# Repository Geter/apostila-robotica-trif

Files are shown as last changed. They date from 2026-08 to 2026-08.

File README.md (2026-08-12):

# Apostila de Robótica — TRIF 2026

Material didático para o desenvolvimento de robôs **Seguidor de Linha** e **Sumô 500 g** visando a participação no **Torneio de Robótica do IFSP (TRIF)**.

Desenvolvido no âmbito do projeto de Bolsa de Ensino **"Aprendizado baseado em projetos: criando soluções para problemas reais"** — IFSP Câmpus Campos do Jordão.

> **Nota sobre os regulamentos:** o edital e os regulamentos do TRIF 2026 (7ª edição) ainda não foram publicados. Esta apostila utiliza como referência os documentos da 6ª edição (Edital nº 187/2025 e regras revisadas em 28/08/2025), disponíveis na pasta [`regulamentos/`](regulamentos/). Ao serem publicados os documentos de 2026, verifique possíveis mudanças — especialmente dimensões, pesos e especificações técnicas.

## Estrutura do repositório

| Pasta | Conteúdo |
|---|---|
| [`apostila/`](apostila/) | Capítulos da apostila em Markdown |
| [`codigo/testes-unitarios/`](codigo/testes-unitarios/) | Sketches para testar cada componente isoladamente |
| [`codigo/evolutivos/`](codigo/evolutivos/) | Versões progressivas dos programas dos robôs |
| [`codigo/playground/`](codigo/playground/) | Algoritmos simples e abertos à criação do aluno |
| [`codigo/competicao/`](codigo/competicao/) | Algoritmos otimizados para o dia da competição |
| [`modelos-3d/`](modelos-3d/) | Arquivos STL das peças impressas em 3D |
| [`regulamentos/`](regulamentos/) | Edital e regras oficiais do TRIF (referência 2025) |
| [`docs/`](docs/) | Imagens e diagramas utilizados na apostila |

## Sumário da apostila

1. [Apresentação](apostila/00-apresentacao.md)
2. [Capítulo 1 — Eletrônica básica](apostila/01-eletronica-basica.md)
3. [Capítulo 2 — Programação com Arduino](apostila/02-programacao-arduino.md)
4. [Capítulo 3 — Seguidor de linha](apostila/03-seguidor-de-linha.md)
5. [Capítulo 4 — Sumô 500 g](apostila/04-sumo-500g.md)
6. [Capítulo 5 — Montagem e integração](apostila/05-montagem-e-integracao.md)
7. [Capítulo 6 — Testes e desempenho](apostila/06-testes-e-desempenho.md)
8. [Anexos](apostila/anexos.md)

## Plataforma de hardware

Os projetos utilizam **Arduino Micro (ATmega32U4)**, motores **N20** com rodas **StickyMAX S20 22 mm**, módulo sensor **infravermelho de 8 canais**, ponte H **L298N**, regulador **LM2596** e bateria **LiPo 2S 2200 mAh**. A lista completa de materiais está nos [Anexos](apostila/anexos.md).

> 💡 **Sugestão de upgrade:** o **ESP32** é uma alternativa mais moderna, com Bluetooth nativo (útil para a modalidade Sumô RC), mais memória e menor custo. Os códigos exigem pequenas adaptações de pinagem e de leitura analógica (faixa 0–4095).

## Como abrir os códigos

Cada sketch está em sua própria pasta (padrão exigido pela Arduino IDE). Abra o arquivo `.ino` diretamente pela IDE. Selecione a placa **Arduino Micro** em *Ferramentas → Placa*.

## Status

| Item | Situação |
|---|---|
| Seguidor de linha (hardware, peças 3D, códigos) | ✅ Completo |
| Sumô — conceitos, regulamento, sensores, códigos de referência | ✅ Completo |
| Sumô — chassi, bateria e driver de motor | 🚧 **Em desenvolvimento** |
| Fotos da placa de distribuição de energia | 🚧 A adicionar |

## Autoria

Prof. Geterson Policarpo Nunes — IFSP Câmpus Campos do Jordão.
Projeto coordenado em conjunto com o Prof. Marques Moreira de Sousa.

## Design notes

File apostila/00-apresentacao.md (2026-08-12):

# Apresentação

## O que é esta apostila

Esta apostila orienta o desenvolvimento de dois robôs de competição — um **Seguidor de Linha** e um **Sumô de 500 g** — para participação no **Torneio de Robótica do IFSP (TRIF)**, edição 2026. Ela nasceu dentro do projeto de Bolsa de Ensino *"Aprendizado baseado em projetos: criando soluções para problemas reais"*, do IFSP Câmpus Campos do Jordão, e serve de material de apoio às oficinas práticas de robótica realizadas nos laboratórios de Informática e Robótica do câmpus.

> ⚠️ **Referência normativa:** como o edital e os regulamentos do TRIF 2026 ainda não foram publicados, todo o conteúdo normativo desta apostila baseia-se nos documentos da 6ª edição (2025). O histórico do torneio mostra que as regras mudam entre edições — o Sumô, por exemplo, já migrou da categoria 1 kg / 20×20 cm para 500 g / 10×10 cm. **Verifique os documentos oficiais de 2026 assim que forem publicados.**

## Para quem ela foi escrita

Para dois públicos que se encontram nas oficinas:

- **Monitores e bolsistas do projeto** — estudantes do ensino superior ou do técnico integrado que se preparam com a apostila para conduzir as oficinas. O único pré-requisito assumido é lógica de programação básica.
- **Participantes das oficinas** — estudantes que seguirão a apostila como guia de construção dos robôs.

O texto fala diretamente com você, leitor, seja qual for o seu papel. A apostila foi pensada para ser **autossuficiente**: tudo o que é necessário para construir e programar os robôs está aqui ou no repositório que a acompanha.

## Cultura maker: produzir em vez de comprar

O princípio que atravessa todo o material é simples: **tudo o que puder ser produzido, nós produziremos**. O chassi é impresso em 3D. A pista de treino é feita à mão. A placa de distribuição de energia é soldada por você. Comprar pronto é o último recurso, não o primeiro. Essa escolha não é apenas econômica — é pedagógica: quem constrói entende, e quem entende conserta, melhora e cria.

## Como a apostila funciona

**Testes a cada passo.** Todo item prático termina com um bloco **"🧪 Teste o que você fez"** — uma verificação imediata do que foi implementado antes de avançar. Mediu a tensão? O sensor apareceu no monitor serial? O motor girou nos dois sentidos? Nenhum componente entra no robô sem passar no seu teste isolado. Esse é o mesmo princípio dos testes de software profissionais: encontrar o erro cedo, quando ele ainda é pequeno e barato.

**Simule antes de montar.** Nos capítulos 1 e 2, o fluxo de trabalho é sempre: **simular → montar → testar**. Usamos o [Tinkercad](https://www.tinkercad.com/) para experimentar circuitos e códigos virtualmente antes de tocar em qualquer componente físico.

**O problema vem antes da solução.** Cada conteúdo parte de uma necessidade concreta do robô. Você não estuda PWM "porque sim" — estuda porque precisa controlar a velocidade do motor.

**Espaço para as suas soluções.** A apostila entrega caminhos que funcionam, mas deixa deliberadamente espaços de criação: o desafio da placa de distribuição de energia (Capítulo 5), os códigos *playground* com pontos de modificação, e a seção de soluções do aluno, onde cada equipe documenta e justifica as próprias escolhas.

## O objetivo concreto

Ao final do percurso, você terá construído robôs aptos a competir nas modalidades **Robôs Seguidores de Linha** e **Sumô de Robôs (500 g)** do TRIF, com potencial de apresentação na SNCT e em outras competições. Mais importante: terá percorrido o ciclo completo de um projeto de engenharia — do requisito ao teste de desempenho.

## Roteiro de leitura

| Capítulo | Conteúdo | Modo de leitura |
|---|---|---|
| 1 — Eletrônica básica | Fundamentos elétricos, componentes, Arduino, motores | Sequencial |
| 2 — Programação com Arduino | IDE, estrutura de código, entradas/saídas, práticas | Sequencial |
| 3 — Seguidor de linha | Projeto completo da modalidade | Por modalidade |
| 4 — Sumô 500 g | Projeto completo da modalidade | Por modalidade |
| 5 — Montagem e integração | Motores, fiação, baterias, desafio de energia | Transversal |
| 6 — Testes e desempenho | Metodologia de testes e preparação para a competição | Fechamento |
| Anexos | Lista de materiais, pinagens, glossário | Consulta |

Os capítulos 1 e 2 são a fundação — leia-os na ordem. Os capítulos 3 e 4 são independentes entre si. Os capítulos 5 e 6 servem aos dois robôs.

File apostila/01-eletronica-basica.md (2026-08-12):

# Capítulo 1 — Eletrônica básica

Antes de qualquer robô andar, existe eletricidade fluindo por fios, resistores, sensores e motores. Este capítulo constrói o vocabulário e as habilidades de bancada que você usará em todo o resto da apostila.

## 1.1 Conceitos fundamentais de eletricidade

### Cargas elétricas

Toda a eletricidade nasce das cargas elétricas presentes na matéria:

- **Próton** — carga positiva ( + )
- **Elétron** — carga negativa ( e⁻ )

Cargas de sinais opostos se atraem; de sinais iguais se repelem. É esse desequilíbrio de cargas que faz tudo funcionar.

### Corrente elétrica

**Corrente elétrica é o movimento ordenado dos portadores de carga** (os elétrons) através de um condutor, como um fio ou barramento. Sem uma "força" que os empurre, os elétrons livres de um fio de cobre vagam desordenadamente; quando aplicamos uma diferença de potencial, eles passam a se mover de forma orientada — e isso é corrente.

A corrente é medida em **ampères (A)**:

- 1 ampère = 1 coulomb por segundo
- 1 coulomb = 6,25 × 10¹⁸ elétrons

A corrente pode ser medida com o auxílio de um **multímetro**.

> ⚠️ **Segurança:** é a **corrente** que mata, não a tensão. A tensão por si só, sem circular corrente, não causa dano — o choque elétrico é originado por uma corrente proveniente de uma diferença de potencial. Trate qualquer circuito energizado com respeito.

**Corrente contínua (CC/DC)** flui sempre no mesmo sentido — é o caso de pilhas, baterias e de tudo nos nossos robôs. **Corrente alternada (CA/AC)** inverte o sentido periodicamente — é a da tomada da sua casa. Nesta apostila, trabalharemos exclusivamente com corrente contínua.

### Tensão (diferença de potencial)

A **tensão** é a "pressão elétrica" que empurra os elétrons. É medida em **volts (V)**. Exemplos do cotidiano: uma bateria de carro tem 12 V; a tomada, 127 V ou 220 V. No robô, trabalharemos com tensões entre 5 V e 8,4 V.

### Resistência elétrica

**Resistência é a capacidade de um condutor de se opor e dificultar a passagem da corrente elétrica.** Ela é obtida por meio de **resistores**, componentes que transformam energia elétrica em energia térmica. A resistência é medida em **ohms**, cujo símbolo é **Ω** (ex.: 1 kΩ = 1000 Ω).

### A Lei de Ohm

A relação entre as três grandezas é a lei mais importante da eletrônica:

```
V = R × I
```

| Grandeza | Símbolo | Unidade |
|---|---|---|
| Tensão | V (ou U) | volt (V) |
| Corrente | I | ampère (A) |
| Resistência | R | ohm (Ω) |

Do triângulo da Lei de Ohm derivam as três formas: `V = I × R`, `I = V / R` e `R = V / I`.

**Exemplo resolvido:** você tem uma bateria de 9 V e quer que uma corrente de 0,05 A flua por um resistor. Qual resistência usar?

```
R = V / I = 9 / 0,05 = 180 Ω
```

### Prefixos métricos

Na eletrônica, os números variam de milionésimos a milhões — por isso usamos prefixos:

| Prefixo | Símbolo | Fator |
|---|---|---|
| mega | M | ×1.000.000 |
| quilo | k | ×1.000 |
| — | — | ×1 |
| mili | m | ÷1.000 |
| micro | µ | ÷1.000.000 |

Exemplos: 1.000 volts = 1 kV; 0,003 ampères = 3 mA.

### ✏️ Exercícios

1. Determine a diferença de potencial em um fio condutor com resistência de 20 Ω, por onde passa uma corrente de 5 A.
2. Um engenheiro projeta um sistema de iluminação com lâmpadas LED. Cada lâmpada opera com 12 V e consome 0,5 A. Qual é a resistência elétrica de cada lâmpada?
3. Um equipamento funciona com corrente de 5 A sob 220 V. A empresa mudou-se para um local com rede de 127 V. Considerando a resistência constante, qual será a nova corrente aproximada?
4. Reescreva utilizando prefixos métricos: 1.000 volts; 0,003 ampères; 1.000 GB.

*Pratique mais: [Toda Matéria — exercícios sobre Lei de Ohm](https://www.todamateria.com.br/exercicios-sobre-lei-de-ohm/)*

## 1.2 Circuitos elétricos

### Circuito aberto e fechado

Um **circuito** é o caminho por onde a corrente circula: fonte → condutor → carga → retorno à fonte. Se o caminho está completo, o circuito está **fechado** e a corrente flui. Qualquer interrupção — uma chave desligada, um fio solto — deixa o circuito **aberto** e a corrente cessa. A chave liga/desliga do seu robô fará exatamente isso.

### Associação de resistores

Resistores podem ser conectados **em série** (um após o outro) ou **em paralelo** (conectados em pontos comuns). A forma de conexão determina a resistência total do circuito:

- **Série:** a resistência equivalente é a soma — `Req = R1 + R2 + ...`. A mesma corrente atravessa todos; a tensão se divide entre eles.
- **Paralelo:** para dois resistores — `Req = (R1 × R2) / (R1 + R2)`. A tensão é a mesma em todos; a corrente se divide.
- **Misto:** combinação dos dois casos; resolve-se por partes.

**Exemplo resolvido (série):** 20 Ω e 30 Ω em série com bateria de 30 V → `Req = 50 Ω`, corrente `I = 30/50 = 0,6 A`.

**Exemplo resolvido (paralelo):** 30 Ω e 20 Ω em paralelo → `Req = (30×20)/(30+20) = 600/50 = 12 Ω`.

### Potência elétrica

**Potência** é a taxa de consumo de energia por segundo, medida em **watts (W)** — 1 W = 1 joule por segundo. Na eletricidade:

```
P = V × I
```

**Exemplo:** um circuito com d.d.p. de 20 V e resistor de 100 Ω. Primeiro `I = 20/100 = 0,2 A`; então `P = 20 × 0,2 = 4 W`.

A potência importa no robô: é ela que define quanto os componentes esquecem, quanto a bateria dura e se o regulador de tensão precisa de dissipador.

### ✏️ Exercício

Quatro resistores distintos são associados em série: R1 = 100 Ω, R2 = 50 Ω, R3 = 20 Ω e R4 = 25 Ω, com U = 30 V. Obtenha: (a) a resistência equivalente; (b) a corrente do circuito; (c) as tensões em cada resistor; (d) a potência do sistema.

## 1.3 Ferramentas de bancada

**Protoboard (matriz de contato):** placa de furos interligados internamente que permite montar circuitos sem solda. As linhas laterais (barramentos) distribuem alimentação; as colunas centrais conectam componentes. Ideal para experimentar antes de soldar.

**Multímetro:** o instrumento de medição essencial. Mede tensão (V), corrente (A), resistência (Ω) e continuidade (o "bip" que indica caminho fechado). Regras de ouro:

1. Tensão mede-se **em paralelo** com o componente (pontas nos dois lados dele).
2. Corrente mede-se **em série** (o circuito passa *por dentro* do multímetro).
3. Resistência e continuidade medem-se **com o circuito desenergizado**.
4. Confira a escala e as posições das pontas de prova antes de medir.

**Jumpers:** fios com terminais macho/fêmea para conectar módulos e protoboard.

### Simulador Tinkercad

Antes de montar fisicamente, monte virtualmente. O **Tinkercad Circuits** ([tinkercad.com](https://www.tinkercad.com/)) simula protoboard, Arduino, componentes e até o monitor serial — de graça, no navegador. Todo circuito deste capítulo pode (e deve) ser testado lá primeiro: errar no simulador não queima componente.

> 🧪 **Teste o que você fez** — Crie uma conta no Tinkercad, abra um novo circuito e monte: bateria de 9 V + resistor de 180 Ω. Adicione o multímetro virtual e meça a corrente. O valor deve ser ~0,05 A (50 mA) — exatamente o exemplo da seção 1.1. Bateu? Você acabou de validar a Lei de Ohm na prática.

## 1.4 Componentes essenciais

**Resistores:** limitam corrente. O valor é indicado por faixas coloridas no corpo (use uma tabela de código de cores ou meça com o multímetro — medir é mais rápido e à prova de erro).

**LEDs:** diodos emissores de luz. Têm **polaridade**: o terminal maior é o **ânodo (+)** e o menor, o **cátodo (−)**. Ligar invertido não acende (e não queima); ligar **sem resistor em série** queima. Para 5 V, um resistor de 220 Ω a 330 Ω é o padrão.

**Chaves e botões:** interrompem ou fecham o circuito. O **push-button** (chave táctil) fecha o contato apenas enquanto pressionado; a **chave gangorra** mantém o estado.

**Capacitores:** armazenam energia por curtos períodos. No robô, aparecem "acalmando" a alimentação — falaremos deles no Capítulo 5.

> 🧪 **Teste o que você fez** — No Tinkercad e depois na protoboard física: LED + resistor de 220 Ω + fonte de 5 V. O LED deve acender. Inverta o LED: deve apagar (e nada queima — o resistor está lá). Meça a tensão sobre o LED aceso: deve ficar em torno de 1,8–2,2 V.

## 1.5 A placa Arduino

O **Arduino** é uma plataforma de prototipagem: uma placa com microcontrolador, pinos de entrada/saída e conexão USB, programável em uma linguagem baseada em C++. Nesta apostila usamos o **Arduino Micro**, baseado no chip **ATmega32U4**:

| Característica | Arduino Micro |
|---|---|
| Microcontrolador | ATmega32U4 (AVR 8 bits, 16 MHz) |
| Tensão de operação | 5 V |
| Pinos digitais de I/O | 20 |
| Canais PWM | 7 |
| Entradas analógicas | **12** |
| Memória flash | 32 KB |
| SRAM | 2,5 KB |
| Conexão | micro-USB (nativa no chip) |

O Micro foi escolhido por dois motivos: é compacto (cabe no sumô de 10 cm) e tem **12 entradas analógicas** — o suficiente para os 8 canais do sensor de linha, algo que o popular Arduino Uno (6 analógicas) não oferece nativamente.

**Tipos de pino:**

- **Digitais:** leem ou escrevem apenas dois estados — `HIGH` (5 V) ou `LOW` (0 V).
- **Analógicos (A0–A11):** leem tensões intermediárias, convertidas em números de 0 a 1023.
- **PWM (~):** pinos digitais capazes de simular tensões intermediárias ligando e desligando muito rápido — é assim que controlaremos a velocidade dos motores (Capítulo 2).

> 💡 **Sugestão de upgrade — ESP32:** placa mais moderna, com Wi-Fi e Bluetooth nativos, mais memória e custo menor. Exige adaptações: leitura analógica de 0–4095, pinagem diferente e tensão lógica de 3,3 V. Uma excelente evolução após dominar o Micro — e praticamente obrigatória se você quiser controlar o robô pelo celular na modalidade Sumô RC.

## 1.6 Alimentação: baterias e regulação

O robô carrega a própria energia. Nossa fonte é uma **bateria LiPo 2S** (2 células de lítio-polímero em série): tensão nominal de **7,4 V** (8,4 V com carga cheia), 2200 mAh de capacidade. É leve, potente — e exige cuidados sérios de segurança, detalhados no Capítulo 5.

Só que o Arduino e os sensores trabalham com **5 V**. Entra em cena o **regulador de tensão**: um circuito que converte um nível de tensão em outro. Usaremos o módulo **LM2596 Step Down (buck)**:

| Especificação | LM2596 |
|---|---|
| Tensão de entrada | 4,5 a 40 V |
| Tensão de saída | 1,5 a 36 V, ajustável por trimpot |
| Regra de operação | entrada ≥ saída + 1,5 V |
| Corrente máxima | 3 A |
| Dissipador | recomendado acima de 15 W |

"Step down" significa que a saída é sempre **menor** que a entrada (o inverso é o "step up"). No robô: bateria 7,4 V → LM2596 ajustado para **5,0 V** → Arduino e sensores.

> 🧪 **Teste o que você fez** — Ajuste do LM2596 (procedimento obrigatório antes de conectar qualquer carga):
> 1. Conecte apenas a **entrada** do módulo à bateria (saída sem nada).
> 2. Ligue o multímetro (escala 20 V DC) na saída.
> 3. Gire o trimpot com uma chave pequena observando o display. **Atenção:** o trimpot é multivoltas — em módulos novos pode ser preciso girar dezenas de voltas no sentido anti-horário até a tensão começar a responder.
> 4. Ajuste até ler **5,0 V** estáveis.
> 5. Só então conecte a carga.
>
> Anote a tensão da bateria e a da saída no seu diário de bordo.

## 1.7 Motores DC e ponte H

**Motores DC** giram quando alimentados; invertendo a polaridade, invertem o sentido. Nosso motor é o **N20**, um micro motor com caixa de redução integrada (o conceito de redução é aprofundado no Capítulo 5).

O Arduino, porém, **não pode alimentar um motor diretamente** — seus pinos fornecem no máximo ~40 mA, e um motor exige centenas de mA. A solução é a **ponte H**, um circuito que usa o sinal fraco do Arduino para chavear a corrente forte da bateria, controlando sentido e velocidade. Usaremos o módulo **L298N**:

| Especificação | L298N |
|---|---|
| Tensão de operação (motores) | 6 a 35 V |
| Corrente máxima | 2 A por canal (4 A total) |
| Canais | 2 motores DC |
| Controle de sentido | pinos IN1–IN4 (sinais digitais) |
| Controle de velocidade | pinos ENA/ENB (sinal PWM) |
| Dimensões | ~43 × 43 × 27 mm |

> ⚠️ **Queda de tensão:** o L298N "come" de 1,4 a 2,5 V entre a entrada e o motor. Com a LiPo em 7,4–8,4 V, o motor recebe cerca de 5,4–6,4 V — exatamente a faixa nominal do N20 de 6 V. Por isso, no nosso robô, **a bateria alimenta o L298N diretamente**, sem passar pelo LM2596. A arquitetura completa:

```
                    ┌── LM2596 (5 V) ──→ Arduino Micro + sensores
LiPo 2S ── chave ───┤
                    └── direto ───────→ L298N ──→ motores N20
```

Essa separação tem um bônus: o ruído elétrico gerado pelos motores fica isolado do circuito de lógica e dos sensores.

> 🧪 **Teste o que você fez** — Ainda sem código (isso vem no Capítulo 2), faça o teste elétrico do L298N: alimente o módulo com a bateria (12 V máx. aqui), conecte um motor N20 na saída A e ligue o pino IN1 em 5 V e IN2 em GND (com ENA com o jumper de fábrica). O motor deve girar. Inverta IN1/IN2: gira ao contrário. Você acabou de operar uma ponte H manualmente.

## O que você leva deste capítulo

Tensão empurra, corrente flui, resistência segura — e a Lei de Ohm amarra as três. Você sabe medir com multímetro, montar em protoboard, simular no Tinkercad, e conhece cada bloco de energia e força do robô: bateria, regulador, ponte H e motor. No próximo capítulo, o Arduino ganha vida por código.

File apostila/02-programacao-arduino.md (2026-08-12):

# Capítulo 2 — Programação com Arduino

O hardware do Capítulo 1 só ganha comportamento por meio de código. Aqui você aprende a linguagem do Arduino do zero até controlar motores — sempre no ciclo **simular → montar → testar**.

## 2.1 A IDE do Arduino e o primeiro upload

1. Baixe a **Arduino IDE** em [arduino.cc/en/software](https://www.arduino.cc/en/software) e instale.
2. Conecte o Arduino Micro pelo cabo micro-USB.
3. Em *Ferramentas → Placa*, selecione **Arduino Micro**. Em *Ferramentas → Porta*, selecione a porta que apareceu.
4. Abra *Arquivo → Exemplos → 01.Basics → Blink* e clique em **Carregar** (seta →).

> ⚠️ **Comportamento normal do Micro no upload:** como a USB do ATmega32U4 é nativa no próprio chip, a placa **se desconecta e reconecta** durante a gravação — a porta "some" da lista por alguns segundos e o sistema pode tocar o som de dispositivo removido. Não é defeito. Se um upload falhar, pressione o botão de reset da placa no momento em que a IDE exibir "Carregando..." e tente novamente.

> 🧪 **Teste o que você fez** — O LED da placa deve piscar em intervalos de 1 segundo. Isso valida de uma vez: instalação da IDE, driver, cabo, placa e processo de upload. Guarde este teste — ele será seu "o Arduino está vivo?" para sempre.

## 2.2 Estrutura de um sketch

Todo programa Arduino (chamado de *sketch*) tem duas funções obrigatórias:

```cpp
void setup() {
  // executa UMA vez, quando a placa liga ou reseta
  // aqui configuramos pinos, serial, bibliotecas
}

void loop() {
  // executa em repetição infinita, o mais rápido possível
  // aqui vive o comportamento do robô
}
```

Pense assim: `setup()` é a preparação; `loop()` é a vida do robô — ler sensores, decidir, acionar motores, milhares de vezes por segundo.

## 2.3 Variáveis, condicionais e laços

A linguagem do Arduino é **C++**. O essencial para os robôs:

```cpp
// Tipos de variáveis mais usados
int   velocidade = 150;      // números inteiros (-32768 a 32767)
long  tempo = 0;             // inteiros grandes
bool  linhaDetectada = true; // verdadeiro/falso
float tensao = 7.4;          // números com vírgula

// Constantes: valores que não mudam (pinos, ajustes)
const int PINO_LED = 13;
#define VELOCIDADE_MAXIMA 255

// Condicionais: o "cérebro" das decisões
if (linhaDetectada) {
  // faz algo
} else if (velocidade > 100) {
  // faz outra coisa
} else {
  // caso contrário
}

// Laço: repete enquanto a condição valer
for (int i = 0; i < 8; i++) {
  // executa 8 vezes (i = 0, 1, ... 7) — ler 8 sensores, por exemplo
}
```

## 2.4 Entradas e saídas

### Saída digital — acendendo um LED

LEDs são dispositivos semicondutores que emitem luz quando percorridos por corrente. Lembre-se da polaridade (ânodo +, cátodo −) e do resistor em série. Para controlar um LED por código, usamos uma porta digital e a função `digitalWrite()`:

```cpp
const int PINO_LED = 13;

void setup() {
  pinMode(PINO_LED, OUTPUT);      // declara o pino como saída
}

void loop() {
  digitalWrite(PINO_LED, HIGH);   // 5 V no pino: LED acende
  delay(500);                     // espera 500 ms
  digitalWrite(PINO_LED, LOW);    // 0 V: LED apaga
  delay(500);
}
```

### Entrada digital — lendo um botão

O **push-button** fecha um circuito quando pressionado. Lendo o pino com `digitalRead()`, o código descobre o estado:

```cpp
const int PINO_BOTAO = 5;

void setup() {
  pinMode(PINO_BOTAO, INPUT_PULLUP); // resistor interno: pino fica HIGH solto,
}                                    // e vai a LOW quando o botão (ligado ao GND) é pressionado

void loop() {
  if (digitalRead(PINO_BOTAO) == LOW) {
    // botão pressionado
  }
}
```

### Bounce e debounce

Ao pressionar um botão **uma única vez**, o contato metálico vibra e o microcontrolador pode entender vários acionamentos — esse ruído se chama **bounce**, e causa problemas sempre que o código precisa contar acionamentos. A solução, o **debounce**, ignora mudanças de estado que ocorram num intervalo menor que um tempo mínimo (tipicamente 50 ms), usando a função `millis()` — que retorna quantos milissegundos se passaram desde que o programa começou:

```cpp
bool estadoLed = LOW;
bool leituraAnterior;
bool leituraAtual;
long ultimoTempoPressionado = 0;
long intervaloDebounce = 50;   // ms — ajuste conforme a necessidade

void setup() {
  pinMode(13, OUTPUT);
  pinMode(12, INPUT);
  leituraAtual = digitalRead(12);
}

void loop() {
  leituraAnterior = leituraAtual;
  leituraAtual = digitalRead(12);

  // só aceita a borda se passou tempo suficiente desde a última
  if (leituraAnterior == HIGH && leituraAtual == LOW
      && millis() - ultimoTempoPressionado > intervaloDebounce) {
    estadoLed = !estadoLed;
    digitalWrite(13, estadoLed);
    ultimoTempoPressionado = millis();
  }
}
```

O botão de largada do seu robô usará exatamente essa técnica.

### Entrada analógica

Sensores analógicos entregam tensões intermediárias. `analogRead()` converte 0–5 V em um número de **0 a 1023**:

```cpp
int leitura = analogRead(A0);   // 0 (0 V) a 1023 (5 V)
```

O **monitor serial** é a janela para enxergar essas leituras. Inicialize com `Serial.begin(9600);` no `setup()` e imprima com `Serial.println(leitura);`. Abra o monitor pela lupa no canto da IDE.

> ⚠️ **Particularidade do Micro:** no ATmega32U4, `Serial` é a **porta USB nativa** (monitor serial do computador) e `Serial1` são os **pinos físicos TX/RX**. Tutoriais escritos para o Uno funcionam normalmente com `Serial`; apenas ao conectar um módulo serial externo (ex.: Bluetooth) você usará `Serial1`.

### Saída "analógica" — PWM

Pinos PWM simulam tensões intermediárias ligando e desligando o pino milhares de vezes por segundo. `analogWrite(pino, valor)` aceita **0 a 255**:

```cpp
analogWrite(9, 128);   // ~50% da potência — meia velocidade no motor
```

A função `map()` converte entre faixas — útil para transformar uma leitura analógica (0–1023) em PWM (0–255):

```cpp
int pwm = map(leitura, 0, 1023, 0, 255);
```

## 2.5 Funções e organização do código

Conforme o código cresce, agrupar comportamentos em funções mantém tudo legível — e no robô isso é vital:

```cpp
// Constantes de pinos agrupadas no topo: um único lugar para ajustar
const int ENA = 9, IN1 = 2, IN2 = 3;

void frente(int velocidade) {
  digitalWrite(IN1, HIGH);
  digitalWrite(IN2, LOW);
  analogWrite(ENA, velocidade);
}

void parar() {
  digitalWrite(IN1, LOW);
  digitalWrite(IN2, LOW);
}

void loop() {
  frente(200);
  delay(1000);
  parar();
  delay(1000);
}
```

Todos os códigos deste repositório seguem esse padrão: **constantes de ajuste no topo**, funções curtas com nome que diz o que fazem, e comentários em português.

## 2.6 Práticas guiadas

Cada prática deve ser feita **primeiro no Tinkercad**, depois no hardware real. Os sketches completos estão em [`codigo/testes-unitarios/`](../codigo/testes-unitarios/).

### Prática 1 — Semáforo

Monte três LEDs (verde, amarelo, vermelho) com seus resistores e programe o ciclo de um semáforo. **Desafio extra:** adicione um push-button de pedestre que, pressionado, antecipe o vermelho.

> 🧪 **Teste o que você fez** — O ciclo respeita os tempos programados? O botão responde a um único toque (debounce funcionando)?

### Prática 2 — Leitura de sensor no monitor serial

Monte um potenciômetro no pino A0 e imprima a leitura no monitor serial. Gire e observe os valores de 0 a 1023.

> 🧪 **Teste o que você fez** — Extremo anti-horário ≈ 0, extremo horário ≈ 1023? Anote os valores reais: nenhum componente é perfeito, e conhecer o "zero real" de um sensor é a essência da **calibração** — conceito central no seguidor de linha.

### Prática 3 — Controle de brilho com PWM

Use a leitura do potenciômetro para controlar o brilho de um LED em um pino PWM, com `map()` convertendo 0–1023 em 0–255.

### Prática 4 — Motor com ponte H

Monte o L298N conforme o Capítulo 1 e controle um motor N20 por código: frente, ré, variação de velocidade por PWM. Sketch de referência: [`03_motor_unico_l298n`](../codigo/testes-unitarios/03_motor_unico_l298n/).

> 🧪 **Teste o que você fez** — O motor: gira nos dois sentidos? Para quando comandado? Em PWM 100 gira visivelmente mais devagar que em 255? Em PWM muito baixo (< 60) ele pode nem girar — anote esse limiar: é o **PWM mínimo de partida** do seu motor, um número que você usará nos códigos do robô.

### Prática 5 — Dois motores

Evolua para os dois motores (saídas A e B do L298N) e crie as funções `frente()`, `re()`, `girarEsquerda()`, `girarDireita()` e `parar()`. Sketch: [`04_dois_motores`](../codigo/testes-unitarios/04_dois_motores/).

> 🧪 **Teste o que você fez** — Com o robô **suspenso** (rodas no ar): cada função faz o esperado? Os dois motores giram na mesma velocidade visualmente? Se um for mais lento, anote — a correção por software virá no Capítulo 3.

## O que você leva deste capítulo

Você programa entradas e saídas digitais e analógicas, domina PWM, debounce e monitor serial, e organiza código em funções com constantes no topo. O Arduino deixou de ser uma placa e virou uma ferramenta. Agora, aos robôs.

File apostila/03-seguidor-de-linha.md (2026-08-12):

# Capítulo 3 — Seguidor de linha

O seguidor de linha é a porta de entrada clássica da robótica de competição: um robô autônomo que percorre, no menor tempo possível, um circuito marcado por uma linha no chão. Simples de enunciar, rico de resolver — envolve eletrônica, mecânica, algoritmos e muito ajuste fino.

## 3.1 A modalidade e o regulamento

> ⚠️ Resumo baseado nas **regras do TRIF 2025** (documento completo em [`regulamentos/`](../regulamentos/)). Confirme as regras de 2026 quando publicadas.

**Como funciona a competição:**

- Robô **totalmente autônomo**, com todos os componentes embarcados. Controle externo só para iniciar ou ajustar parâmetros entre tentativas.
- Vence **a volta válida mais rápida** entre todas as tomadas de tempo.
- Cada tomada de tempo dura no máximo **5 minutos**, com **3 tentativas consecutivas**.
- Uma volta é válida quando o robô percorre todo o percurso, **para automaticamente** dentro da área de partida-chegada, sobre a linha, e **permanece parado por pelo menos 2 segundos**.

**O robô:**

| Regra | Valor |
|---|---|
| Dimensões máximas | 250 × 250 × 200 mm |
| Peso | livre |
| Controle | autônomo |
| Downforce (turbina/ventoinha) | permitido, desde que dentro das dimensões |
| Produtos nos pneus para aumentar tração | **proibido** |

**A pista:**

| Característica | Valor |
|---|---|
| Superfície | manta emborrachada **preta** |
| Linha | **branca**, 19 ± 1 mm de largura |
| Comprimento total | até 60 m |
| Geometria | retas e arcos; raio mínimo de 100 mm |
| Cruzamentos | a 90 ± 5°, com retas de 250 mm antes e depois |
| Desníveis tolerados | ± 3 mm; inclinações de até 5° |
| Marcações | **à direita** da linha: partida e chegada; **à esquerda**: mudanças de curvatura |
| Chegada | 1 m atrás da partida, na mesma reta |

> 💡 **Atenção ao detalhe que derruba iniciantes:** em competição a linha é **branca sobre fundo preto** — o oposto da maioria dos tutoriais da internet (linha preta sobre branco). Toda a calibração e a lógica dos nossos códigos já consideram isso.

## 3.2 O sensor de linha: infravermelho refletivo

### Como funciona

Cada canal do sensor tem um par: um **LED emissor infravermelho** e um **fototransistor receptor**. O LED ilumina o chão; o receptor mede quanto refletiu. Superfície **branca reflete muito** (leitura baixa em módulos típicos), superfície **preta absorve** (leitura alta). Comparando as leituras dos canais, o robô descobre **onde a linha está** sob ele.

### Nosso módulo: barra IR de 8 canais

| Especificação | Valor |
|---|---|
| Canais | 8 (saídas analógicas) |
| Dimensões | 66–71 × 16–17 × 4 mm (varia por fabricante) |
| Tensão de operação | 3,3–5 V |
| Consumo | ~100 mA |
| Distância ideal de detecção | **3 mm** |
| Distância máxima | 6 a 9,5 mm |

Por que **8 canais**? Com a linha de 19 mm e sensores espaçados ~8–9 mm, sempre 2 a 3 canais enxergam a linha simultaneamente — o que permite saber a posição dela com precisão e detectar cruzamentos e marcações.

> É por causa desses 8 canais analógicos que usamos o Arduino **Micro** (12 entradas analógicas) e não o Uno (apenas 6).

### Leitura crua

Primeiro passo de qualquer sensor: **ver o que ele vê**. O sketch [`02_leitura_sensor_ir`](../codigo/testes-unitarios/02_leitura_sensor_ir/) imprime os 8 canais no monitor serial.

> 🧪 **Teste o que você fez** — Com o módulo a ~3–5 mm de uma superfície: passe uma folha branca e uma superfície preta sob os sensores e observe os valores. Anote os números típicos de **branco** e de **preto** do *seu* módulo. Há diferença clara entre eles (algumas centenas de unidades)? Se as leituras mal mudam, verifique a distância ao solo e a alimentação.

### Calibração

Módulos reais não são uniformes: cada canal tem seu próprio "branco" e "preto". **Calibrar** é descobrir o mínimo e o máximo de cada canal e normalizar as leituras para uma escala comum (0–1000). O procedimento, implementado em [`01_calibracao`](../codigo/evolutivos/seguidor/01_calibracao/): ao ligar, o robô passeia os sensores sobre linha e fundo por alguns segundos, registrando extremos por canal.

> 🧪 **Teste o que você fez** — Após calibrar, as leituras normalizadas mostram ~0 sobre o branco e ~1000 sobre o preto **em todos os canais**? Um canal que não calibra (fica travado) indica mau contato ou canal defeituoso — descubra agora, não na pista.

## 3.3 Chassi impresso em 3D

### 3.3.1 O conjunto de peças

O chassi do seguidor é composto por quatro peças impressas, disponíveis em [`modelos-3d/seguidor/`](../modelos-3d/seguidor/):

| Arquivo | Peça | Dimensões |
|---|---|---|
| `chassi_base.stl` | Base principal | 131 × 192 × 3,5 mm |
| `suporte_motor_n20.stl` (×2) | Fixação dos motores | 18 × 22 × 10 mm |
| `suporte_bateria.stl` | Segundo andar / bateria | 131 × 62 × 4 mm |
| `suporte_sensor_ir.stl` | Berço do módulo IR | 78 × 27 × 10 mm |
| `calco_comprimento_5mm.stl` / `calco_largura_1mm.stl` | Calços p/ módulos IR menores | — |

O sistema de fixação dos motores funciona por **sanduíche**: o N20 fica prensado entre a face inferior do chassi e a placa do suporte, com parafusos M3 atravessando as torres de 10 mm. Os furos duplicados no chassi permitem duas posições de montagem.

O suporte do sensor possui cavidade de **71,4 × 17,4 mm** com chanfro de entrada e entalhes de dedo para extração. Módulos menores que 71 × 17 mm usam os calços inclusos para ficarem travados.

O suporte da bateria tem janela de **78 × 24 mm** — dimensionada para a LiPo 2S 2200 mAh (75 × 23 × 18 mm) — e furos de 4 × 4 mm para passagem de velcro/abraçadeira.

### 3.3.2 Geometria e alturas

Com as rodas de 22 mm, a cadeia de alturas do robô fecha assim:

```
Eixo das rodas:              11 mm do solo
Face inferior do chassi:     16 mm do solo
Face do sensor IR:           ~6 mm do solo (limite máximo de detecção!)
```

A solução está na **esfera deslizante** traseira: montada **com o espaçador de 3 mm** incluso no kit, ela eleva a traseira e inclina o nariz do robô para baixo, trazendo o sensor para a faixa de **3–4 mm do solo — a distância ideal**. Montar a esfera **sem** o espaçador inverte a inclinação e piora a leitura: não pule esse detalhe.

### 3.3.3 Parâmetros de impressão

| Parâmetro | Recomendação |
|---|---|
| Material | PLA |
| Altura de camada | 0,2 mm |
| Preenchimento | 25–40 % (chassi); 50 % (suportes de motor) |
| Perímetros | 3 |
| Orientação | todas as peças com a face maior na mesa |
| Suportes | desnecessários |

> 💡 A base de 3,5 mm de espessura é o ponto estruturalmente mais sensível: chassi que flexiona desalinha o sensor. Imprima com pelo menos 3 perímetros e preenchimento não inferior a 25 %. Se notar flexão no robô montado, considere reimprimir com 40 % ou adicionar nervuras — um bom exercício de melhoria para a seção 5.6.

> 🧪 **Teste o que você fez** — Antes de montar: as peças saíram planas (sem warping)? Os furos M3 aceitam o parafuso sem esforço excessivo? O módulo IR entra e sai do berço com o dedo, sem folga perceptível? A bateria passa pela janela do suporte?

### 3.3.4 Montagem mecânica

1. Parafuse os dois suportes de motor com os N20 posicionados (fios voltados para o centro do chassi).
2. Instale as rodas StickyMAX no eixo de 3 mm, travando com o parafuso allen sem cabeça.
3. Monte a esfera deslizante na traseira **com o espaçador de 3 mm** (parafusos M2.5).
4. Encaixe o módulo IR no suporte do sensor (com calços, se necessário) e fixe o conjunto na dianteira; passe o cabo flat pelo rasgo de 40 × 4 mm.
5. Fixe o suporte da bateria e prenda a LiPo com velcro pelas janelas laterais.
6. Posicione L298N, LM2596 e Arduino Micro — a montagem elétrica completa é o assunto do Capítulo 5.

> 🧪 **Teste o que você fez** — Com o robô montado sobre uma superfície plana: as duas rodas e a esfera tocam o chão simultaneamente? O robô rola em linha reta ao ser empurrado? Meça com uma régua a distância do sensor ao solo: está entre 3 e 5 mm?

## 3.4 Lógica de controle

### O problema

A cada instante, o robô precisa responder: *onde está a linha embaixo de mim?* e *o que faço com os motores para centralizá-la?* Toda a evolução dos códigos deste capítulo é o refinamento dessas duas respostas.

### Versão 1 — Liga/desliga por faixas (playground)

A abordagem mais simples que funciona: dividir os 8 sensores em grupos e agir por faixas de posição.

```
linha no CENTRO (sensores 3–4)      → dois motores em velocidade de cruzeiro
linha um pouco à ESQUERDA (2)       → motor direito acelera, esquerdo reduz
linha muito à ESQUERDA (0–1)        → motor direito acelera, esquerdo quase para
(espelhado para a direita)
```

É uma cadeia de `if/else` que qualquer pessoa lê e entende — e o robô **anda de verdade**, serpenteando um pouco. Esse serpenteio não é defeito: é a assinatura visível da limitação do algoritmo, e entender **por quê** ele acontece é o objetivo pedagógico. Código completo e comentado, com pontos de criação marcados: [`playground/seguidor_playground`](../codigo/playground/seguidor_playground/).

> 🧪 **Teste o que você fez** — Na pista de treino: o robô completa uma volta sem sair da linha? Em que tipo de trecho ele mais oscila? Filme e observe: as respostas guiarão seus ajustes.

### Versão 2 — Posição contínua e controle proporcional

Em vez de faixas, calcula-se a **posição exata** da linha por média ponderada das leituras calibradas — um número contínuo (0 a 7000, com 3500 = centro). O **erro** é a distância ao centro, e a correção dos motores passa a ser **proporcional ao erro**: erro pequeno, correção suave; erro grande, correção forte. O serpenteio praticamente desaparece. Implementação progressiva em [`codigo/evolutivos/seguidor/`](../codigo/evolutivos/seguidor/).

### Versão de competição

O código de competição ([`competicao/seguidor_competicao`](../codigo/competicao/seguidor_competicao/)) usa todos os recursos para vencer: leitura calibrada e normalizada, posição por média ponderada, **controle PID completo**, tratamento de cruzamentos, perfis de velocidade e parada automática. Ele está fartamente comentado — estude-o **depois** de dominar o playground: a distância entre "funciona" e "vence" é uma das lições mais valiosas deste projeto.

## 3.5 Parada automática na chegada

O regulamento exige que o robô pare **sozinho** dentro da área de partida-chegada e permaneça imóvel por 2 segundos — uma volta sem parada válida é volta perdida. A marcação de chegada fica **à direita da linha**; a estratégia dos códigos é detectar a assinatura dessa marcação nos sensores da extremidade direita (distinguindo-a de cruzamentos, que ativam os dois lados ao mesmo tempo), avançar alguns centímetros para entrar na área e frear.

> 🧪 **Teste o que você fez** — Reproduza na pista de treino a marcação de partida/chegada nas dimensões oficiais e valide: o robô para após cruzá-la? Para *dentro* da área de 1 m? Fica parado sem "tremer" (motores realmente em zero)? Ele ignora corretamente as marcações de curvatura do lado esquerdo?

## 3.6 Pista de treino

No espírito maker, a pista é feita à mão: manta de borracha ou EVA **preto** (ou lona preta esticada), com a linha aplicada em **fita branca de 19 mm** — fita isolante branca ou fita crepe de qualidade funcionam. Regras de construção derivadas do regulamento: raio mínimo de 100 mm nas curvas, cruzamentos a 90°, marcações laterais de 40 × 19 mm. Comece com um circuito oval simples e evolua para traçados com cruzamentos e sequências de curvas.

> 🧪 **Teste o que você fez** — Passe o teste de leitura crua (3.2) sobre a *sua* pista: o contraste entre a fita e o fundo é comparável ao do papel branco/preto usado na calibração? Fitas foscas funcionam melhor que brilhantes (reflexo especular engana o sensor).

## O que você leva deste capítulo

Um seguidor de linha completo — regulamentado, montado, calibrado e programado em dois níveis (playground e competição) — e a compreensão do porquê de cada decisão de projeto. Os testes de desempenho e a preparação para o dia da prova ficam no Capítulo 6.

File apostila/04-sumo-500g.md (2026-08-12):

# Capítulo 4 — Sumô 500 g

Dois robôs, uma arena circular, um objetivo: empurrar o oponente para fora. O sumô de robôs simula o esporte japonês homônimo e existe em duas variantes no TRIF: **Rádio Controlado (RC)**, operado por uma pessoa, e **Autônomo (Auto)**, que luta sozinho. Este capítulo cobre as duas.

## 4.1 A modalidade e o regulamento

> ⚠️ Resumo baseado nas **regras do TRIF 2025** — categoria **Mini Sumô (500 g)** (documento completo em [`regulamentos/`](../regulamentos/)). Confirme as regras de 2026 quando publicadas.

**O robô:**

| Regra | Valor |
|---|---|
| Dimensões máximas | **10 × 10 cm** (comprimento × largura), altura livre |
| Peso máximo | **500 g** (tolerância da balança **não** é considerada) |
| Caixa de inspeção | 205 × 205 mm — o robô deve entrar e sair sem esforço |
| Fixação ao dohyo (ventosa, cola) | **proibido** |
| Lâminas | não podem quebrar em partes durante a luta |
| Proibições | laser/flash/IR perturbador, líquidos, ignição, arremesso, danos ao dohyo |

**A arena (dohyo):**

| Elemento | Especificação |
|---|---|
| Dohyo | placa circular de madeira, **77 cm** de diâmetro, fórmica preta, 2,5 cm de altura |
| Tawara (borda) | linha **branca** circular de **2,5 cm** de largura (faz parte do dohyo) |
| Shikiri-sen | duas linhas marrons de 1 × 10 cm, a 5 cm do centro (posição inicial dos robôs) |

**A partida:**

- 3 *rounds* de 1 minuto; vence quem marcar 2 pontos **Yuko** primeiro.
- Ponto Yuko: fazer o oponente tocar **qualquer parte fora do dohyo**.
- Robô imóvel após contagem de 3 do juiz = **Shinitai** (ponto para o oponente).
- Intervalo entre rounds: 30 s (permitida alteração de rotina no Autônomo; **proibida** troca de bateria/peças).
- Segurança: **óculos de proteção, calças e calçados fechados** são obrigatórios para competir.

**Regras específicas do tipo RC:** rádio em **2,4 GHz** (Bluetooth apenas **Classe 1, comprovado por datasheet**; smartphones como controle são **proibidos**). Um único sistema de controle (PCS) por robô.

**Regras específicas do tipo Autônomo:** o robô inicia e para **pelo Controle Remoto do Juiz** — este é o assunto da seção 4.5.

## 4.2 Projetando dentro de 10 × 10 cm e 500 g

O envelope do mini sumô é implacável: **10 × 10 cm é menor que a palma da mão**. Cada componente disputa espaço e peso. O orçamento de massa aproximado:

| Item | Massa estimada |
|---|---|
| 2 × motor N20 | ~20 g |
| Rodas | ~17 g |
| Arduino Micro | ~13 g |
| Eletrônica (driver, regulador, sensores) | ~30–50 g |
| Bateria | *(em definição — ver 4.7)* |
| Chassi + lâmina | restante do orçamento |

Dois princípios de projeto dominam a categoria:

1. **Centro de massa baixo e à frente** — quem "entra por baixo" do oponente com uma rampa/lâmina vence o empurra-empurra.
2. **Tração é tudo** — todo grama sobrando vira lastro sobre as rodas; a redução dos motores privilegia **torque** (ver o experimento de reduções no Capítulo 5).

> ⚠️ O **L298N não serve para o sumô**: seus 43 × 43 × 27 mm consomem quase metade da área útil. O driver definitivo do sumô está em definição (seção 4.7) — candidatos naturais são módulos compactos como TB6612FNG ou DRV8833 (~20 × 15 mm). Da mesma forma, a LiPo 2S 2200 mAh do seguidor pesa ~100 g (20 % do orçamento!) — o sumô usará uma bateria menor.

## 4.3 Chassi impresso em 3D

> 🚧 **Em desenvolvimento.** O chassi do robô sumô é um projeto independente do seguidor de linha e será desenvolvido especificamente para o envelope 10 × 10 cm / 500 g, contemplando rampa frontal, fixação dos N20, bateria e eletrônica. Os arquivos e esta seção serão atualizados em commit futuro. Requisitos já definidos:
>
> - Envelope rígido de 100 × 100 mm (deve entrar e sair da caixa de inspeção sem esforço);
> - Rampa/lâmina frontal em ângulo raso, sem materiais que quebrem em partes;
> - Posições para 2 × N20, driver compacto, bateria e sensores de borda nas extremidades;
> - Centro de massa o mais baixo e frontal possível.

## 4.4 Sensores do sumô

### Sensores de borda (linha branca)

O mesmo princípio IR refletivo do seguidor de linha, agora com outra missão: detectar a **Tawara** (borda branca) antes de cair. Dois sensores IR individuais (ex.: TCRT5000) nas quinas dianteiras são o mínimo; quatro (dianteira + traseira) dão segurança na ré. Sobre a fórmica preta a leitura é alta; ao alcançar o branco, despenca — é o gatilho para a manobra de escape.

Teste isolado: [`06_sensor_borda`](../codigo/testes-unitarios/06_sensor_borda/).

> 🧪 **Teste o que você fez** — Simule a Tawara com fita branca sobre fundo preto. As leituras de fundo e de borda têm separação clara? Defina e anote o **limiar** (`LIMIAR_BORDA`) do seu sensor: um valor entre os dois grupos, mais próximo do fundo preto (detectar cedo é melhor que tarde — a borda tem só 2,5 cm).

### Sensor de oponente

Para achar o adversário num círculo de 77 cm, as opções usuais:

| Sensor | Alcance | Saída | Observação |
|---|---|---|---|
| IR de distância digital (ex.: E18-D80NK) | até ~80 cm ajustável | digital | simples e rápido — nossa referência |
| Ultrassônico (HC-SR04) | 2–400 cm | pulso | mais lento; cone largo |
| IR analógico (Sharp GP2Y0A21) | 10–80 cm | analógica | dá a distância, não só presença |

Um sensor frontal é o mínimo; dois em leque ampliam o campo de busca. Teste isolado: [`07_sensor_oponente`](../codigo/testes-unitarios/07_sensor_oponente/).

> 🧪 **Teste o que você fez** — Aponte o sensor para um alvo do tamanho de um robô (caixa de ~10 cm) e meça o alcance real de detecção, aproximando e afastando. Objetos escuros e foscos são detectados a menor distância que claros — anote os dois alcances.

## 4.5 O Controle Remoto do Juiz (start/stop por IR)

Na categoria Autônomo, **quem dá a largada é o juiz**, por um controle remoto infravermelho. O regulamento define:

- Luz infravermelha, comprimento de onda **950 nm**, portadora de **38–40 kHz**;
- Qualquer **controle remoto da marca Sony** pode gerar o sinal;
- Três estados: **Tecla 1 = Pronto**, **Tecla 2 = Start**, **Tecla 3 = Stop**;
- O estado **Stop é permanente**: para reiniciar, o operador desliga e religa a eletrônica do robô.

Na prática, o robô precisa de um **receptor IR de 38 kHz** (ex.: VS1838B/TSOP38238) e de código que decodifique o protocolo Sony (SIRC). Usamos a biblioteca **IRremote**. O fluxo do robô:

```
AGUARDANDO  → recebeu START → LUTANDO
LUTANDO     → recebeu STOP  → TRAVADO (só sai desligando e religando)
```

Teste isolado (que também serve para **descobrir os códigos** do controle usado no treino): [`08_receptor_ir_juiz`](../codigo/testes-unitarios/08_receptor_ir_juiz/).

> 💡 A organização do TRIF já disponibilizou em edições anteriores os arquivos de programação, esquemas elétricos e PCBs de um sistema de microstart oficial — consulte a página do evento ([ifsp.edu.br/trif](https://www.ifsp.edu.br/trif)).

> 🧪 **Teste o que você fez** — Com um controle Sony (ou controle universal em modo Sony), pressione as teclas 1, 2 e 3 apontando para o receptor: o monitor serial mostra três códigos distintos e **estáveis** (o mesmo código a cada repetição da mesma tecla)? Anote-os — são as constantes do seu código de competição. O robô responde ao sinal a pelo menos 1 m de distância?

## 4.6 Estratégias de combate

### Autônomo: a máquina de três estados

O playground do sumô ([`playground/sumo_playground`](../codigo/playground/sumo_playground/)) implementa a estratégia mínima que ganha luta:

```
PROCURANDO: gira no próprio eixo até o sensor frontal ver o oponente
ATACANDO:   ambos os motores à frente, velocidade máxima
BORDA:      viu a linha branca → ré + giro → volta a PROCURANDO
```

A prioridade é inegociável: **borda sempre vence** — de nada adianta atacar caindo do dohyo. O código traz pontos de criação marcados: velocidade e sentido da busca, duração do escape, estados extras que você inventar.

A versão de competição ([`competicao/sumo_competicao`](../codigo/competicao/sumo_competicao/)) adiciona: largada explosiva no sinal do juiz, busca ativa (avanço em arco em vez de giro parado), verificação de borda em alta frequência e travamento definitivo no Stop, conforme o regulamento.

### Rádio Controlado

Na variante RC, a "inteligência" é do piloto — o desafio técnico é o enlace de controle dentro das regras (2,4 GHz; Bluetooth só Classe 1 com datasheet; smartphone proibido). Com o Arduino Micro, o caminho é um módulo receptor dedicado; com o **upgrade para ESP32**, o Bluetooth nativo simplifica o projeto — atenção à exigência de Classe 1.

> 🚧 **Em desenvolvimento.** A definição do enlace RC oficial do projeto acompanhará a definição do hardware do sumô (seção 4.7).

## 4.7 Hardware específico do sumô

> 🚧 **Em desenvolvimento.** Os itens abaixo serão definidos e documentados em commit futuro:
>
> - **Driver de motor compacto** (candidatos: TB6612FNG, DRV8833);
> - **Bateria** (LiPo menor que a do seguidor, compatível com o orçamento de 500 g);
> - **Chassi** (seção 4.3) e **dohyo de treino** (construção maker em MDF com fórmica/pintura preta e borda branca).

## O que você leva deste capítulo

As regras do mini sumô, os princípios de projeto do envelope 10 × 10 / 500 g, os três sistemas de sensores (borda, oponente, juiz) testados isoladamente e a estratégia de combate em máquina de estados — pronta para evoluir com as suas ideias. O hardware definitivo será fechado nas próximas atualizações do repositório.

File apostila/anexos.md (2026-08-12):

# Anexos

## A. Lista de materiais (BOM)

### Seguidor de linha

| Item | Qtde | Especificação | Observação |
|---|---|---|---|
| Arduino Micro | 1 | ATmega32U4, micro-USB | 12 entradas analógicas |
| Motor N20 6 V | 2 + extras | reduções variadas (ex.: 1:10, 1:30, 1:50) | extras para o experimento do Cap. 5 |
| Roda StickyMAX S20 | 2 | Ø22 mm, largura 16 mm, furo 3 mm | cubo alumínio + pneu silicone 20 Shore-A |
| Esfera deslizante 3/8" | 1 | altura 15 mm, furos M2.5 a 16 mm | **montar com o espaçador de 3 mm** |
| Módulo sensor IR 8 canais | 1 | saídas analógicas, 3,3–5 V | 66–71 × 16–17 mm |
| Ponte H L298N | 1 | 2 A/canal, 6–35 V | queda interna ~2 V |
| Regulador LM2596 step down | 1 | ajustável, 3 A | ajustar para 5,0 V |
| Bateria LiPo 2S | 1+ | 7,4 V, 2200 mAh, 30C, XT60 | 75 × 23 × 18 mm, ~100 g |
| Carregador balanceado LiPo | 1 | — | uso obrigatório |
| Chave liga/desliga | 1 | corrente ≥ 3 A | modelo à escolha do aluno (desafio 5.4) |
| Conector XT60 fêmea | 1 | painel ou aéreo | desafio 5.4 |
| Bornes, placa ilhada, fios 18–28 AWG, termorretrátil | — | — | desafio 5.4 e fiação geral |
| Push-button, LEDs, resistores 220 Ω–10 kΩ, protoboard, jumpers | — | — | práticas dos Caps. 1–2 |
| Parafusos M3, M2.5 + porcas; velcro | — | — | montagem mecânica |
| Filamento PLA | — | — | impressão das peças |

### Sumô 500 g

| Item | Qtde | Especificação | Observação |
|---|---|---|---|
| Arduino Micro | 1 | — | mesmo do seguidor |
| Motor N20 6 V | 2 | redução privilegiando torque | escolha guiada pelo experimento 5.1 |
| Sensor IR de borda (ex.: TCRT5000) | 2–4 | — | Tawara branca |
| Sensor de oponente (ex.: E18-D80NK) | 1–2 | digital, alcance ajustável | ver alternativas no Cap. 4 |
| Receptor IR 38 kHz (VS1838B/TSOP38238) | 1 | — | controle do juiz (Sony) |
| Driver de motor compacto | 1 | 🚧 **Em desenvolvimento** | candidatos: TB6612FNG, DRV8833 |
| Bateria | 1 | 🚧 **Em desenvolvimento** | LiPo compacta |
| Chassi | 1 | 🚧 **Em desenvolvimento** | envelope 10 × 10 cm |

## B. Pinagem de referência — Arduino Micro

### Seguidor de linha

| Função | Pino |
|---|---|
| Sensor IR canais 1–6 | A0, A1, A2, A3, A4, A5 |
| Sensor IR canal 7 | A6 (pino digital 4) |
| Sensor IR canal 8 | A7 (pino digital 6) |
| L298N IN1 / IN2 (motor esquerdo) | 2 / 3 |
| L298N IN3 / IN4 (motor direito) | 7 / 8 |
| L298N ENA (PWM esq.) | 9 |
| L298N ENB (PWM dir.) | 10 |
| Botão de largada | 5 (INPUT_PULLUP) |
| LED de status | 13 |
| Alimentação | 5 V do LM2596 no pino 5V; GND comum |

> ⚠️ **GND comum:** Arduino, L298N, LM2596 e sensores devem compartilhar o mesmo GND — sem isso, nada de sinal faz sentido.

### Sumô (referência — hardware em definição)

| Função | Pino |
|---|---|
| Sensor de borda esquerdo / direito | A0 / A1 |
| Sensor de oponente (digital) | 12 |
| Receptor IR do juiz | 3 (interrupção) |
| Driver IN1 / IN2 (esq.) | 4 / 5 |
| Driver IN3 / IN4 (dir.) | 6 / 8 |
| Driver PWM esq. / dir. | 9 / 10 |
| LED de status | 13 |

## C. Glossário

**Bounce** — vibração do contato de um botão que gera múltiplos acionamentos falsos; corrigido por *debounce*.
**Buck (step down)** — conversor que reduz tensão CC; nosso LM2596.
**Calibração** — descobrir os valores reais de mínimo e máximo de um sensor para normalizar suas leituras.
**Dohyo** — a arena circular do sumô. *Dohyo Jonai*: zona de batalha; *Dohyo Jogai*: área externa.
**Fusensho** — vitória sem luta (oponente ausente ou robô que não funciona).
**Hansoku / Hansoku-Make** — violação / derrota por violação.
**Keikoku** — advertência; duas advertências = 1 ponto Yuko para o oponente.
**PCS** — sistema de controle proporcional por rádio (sumô RC).
**PWM** — modulação por largura de pulso; simula tensões intermediárias para controlar velocidade/brilho.
**Redução** — relação de engrenagens que troca velocidade por torque.
**Shikiri-sen** — linhas de partida no interior do dohyo.
**Shinitai** — "robô morto": imóvel na arena após contagem do juiz.
**Tawara** — a borda branca circular do dohyo (2,5 cm; parte interna do dohyo).
**Torinaoshi** — revanche/repetição de round determinada pelos juízes.
**Yuko** — o ponto do sumô: fazer o oponente tocar fora do dohyo.
**Yusei** — robô predominante; critério de desempate por iniciativa de luta.

## D. Estrutura do repositório e contribuição

```
apostila-robotica-trif/
├── apostila/          capítulos em Markdown
├── codigo/
│   ├── testes-unitarios/   um sketch por componente
│   ├── evolutivos/         versões progressivas (seguidor e sumô)
│   ├── playground/         algoritmos simples e abertos à criação
│   └── competicao/         algoritmos otimizados para vencer
├── modelos-3d/        STLs (seguidor completo; sumô em desenvolvimento)
├── regulamentos/      documentos oficiais TRIF (referência 2025)
└── docs/              imagens e diagramas
```

Para trabalhar: clone o repositório, crie uma pasta/fork da sua equipe para o diário de testes e as soluções próprias (seção 5.7), e versione seus códigos com commits pequenos e descritivos. Cada sketch fica em pasta homônima ao `.ino` (exigência da Arduino IDE).

## E. Referências e leituras

- Regulamentos oficiais do TRIF — pasta [`regulamentos/`](../regulamentos/) e [ifsp.edu.br/trif](https://www.ifsp.edu.br/trif)
- Tinkercad Circuits — [tinkercad.com](https://www.tinkercad.com/)
- Documentação Arduino — [docs.arduino.cc](https://docs.arduino.cc/)
- Exercícios de Lei de Ohm — [Toda Matéria](https://www.todamateria.com.br/exercicios-sobre-lei-de-ohm/)

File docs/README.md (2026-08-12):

# docs/ — imagens da apostila

Imagens pendentes de adição (referenciadas no texto):

| Arquivo | Referenciado em | Conteúdo |
|---|---|---|
| `placa-distribuicao-topo.jpg` | Cap. 5, seção 5.4 | Placa de distribuição de energia — vista superior |
| `placa-distribuicao-trilhas.jpg` | Cap. 5, seção 5.4 | Placa de distribuição — vista inferior (trilhas) |

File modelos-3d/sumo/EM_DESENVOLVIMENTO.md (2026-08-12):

# Em desenvolvimento — chassi do sumô será adicionado em commit futuro

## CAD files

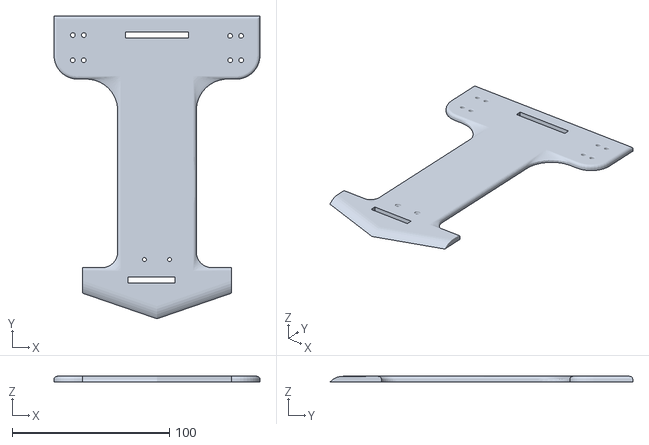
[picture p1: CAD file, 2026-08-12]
modelos-3d/seguidor/chassi_base.stl
131.1 x 192.5 x 3.50

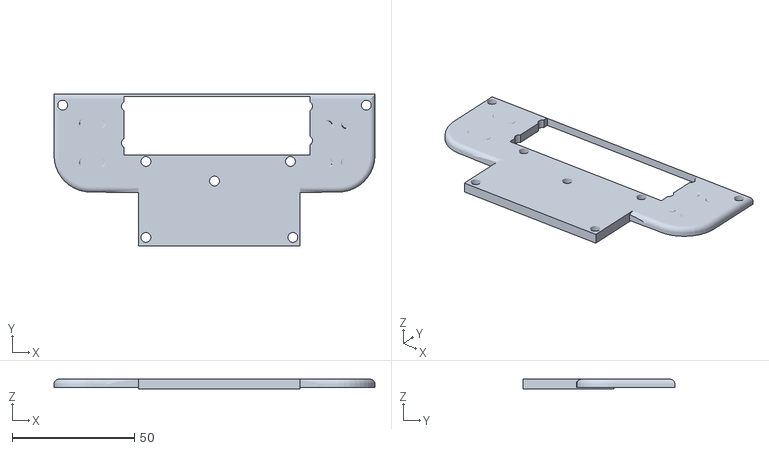
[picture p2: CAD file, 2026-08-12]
modelos-3d/seguidor/suporte_bateria.stl
131.1 x 61.9 x 4.00

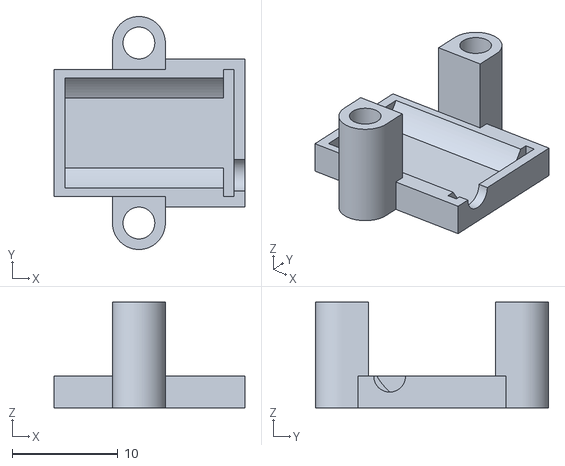
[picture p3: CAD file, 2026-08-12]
modelos-3d/seguidor/suporte_motor_n20.stl
18.0 x 22.0 x 10.0

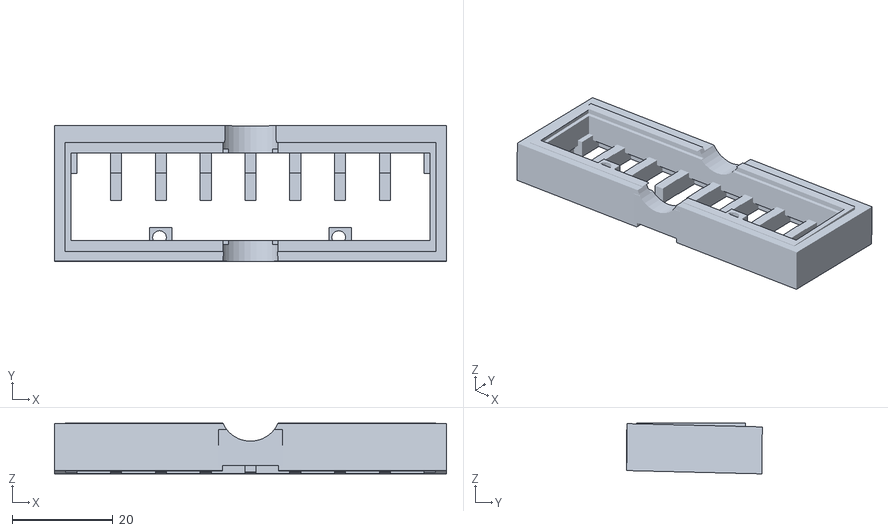
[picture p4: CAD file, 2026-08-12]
modelos-3d/seguidor/suporte_sensor_ir.stl
78.0 x 27.0 x 10.1

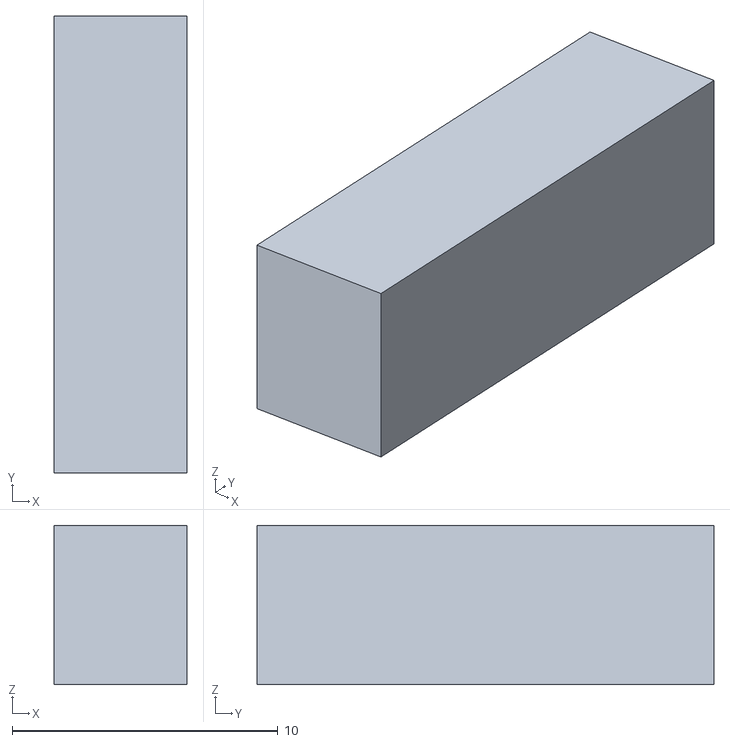
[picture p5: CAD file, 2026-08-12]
modelos-3d/seguidor/calco_comprimento_5mm.stl
5.00 x 17.2 x 6.00

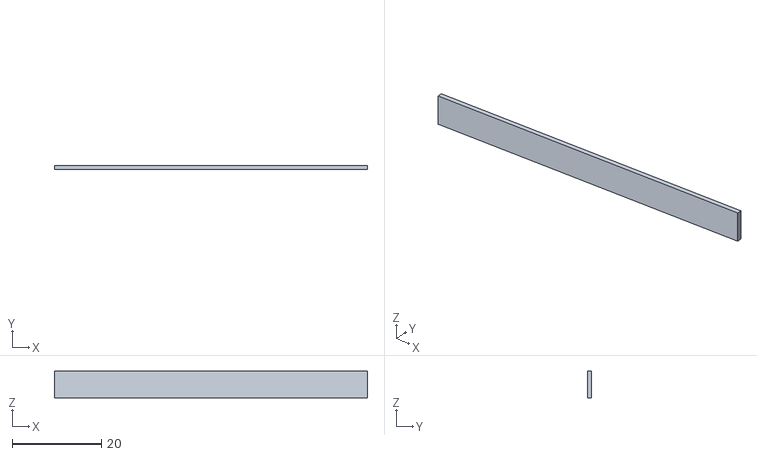
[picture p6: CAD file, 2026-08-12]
modelos-3d/seguidor/calco_largura_1mm.stl
70.0 x 1.00 x 6.00

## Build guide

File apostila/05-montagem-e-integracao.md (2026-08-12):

# Capítulo 5 — Montagem e integração

Um robô não é uma pilha de módulos que funcionam sozinhos: é um **sistema**. Este capítulo trata do que une as partes — motores, fios, energia — e culmina no desafio de projeto que integra tudo. Ele é deliberadamente **informativo sem ser prescritivo**: apresenta o que precisa ser feito e as técnicas disponíveis, mas deixa espaço para você implementar as soluções que julgar melhores.

## 5.1 Motores

### 5.1.1 O motor DC e o N20

O motor de corrente contínua converte energia elétrica em rotação. O **N20** é um micro motor DC com **caixa de redução metálica integrada** — um bloco de ~10 × 12 × 25 mm com eixo de 3 mm, disponível em dezenas de versões que combinam tensão (nós usamos 6 V) e **relação de redução**.

### 5.1.2 O que é redução e para que serve

Um motor DC "puro" gira muito rápido (10.000+ RPM) com **pouquíssimo torque** — força de giro. Ligado direto a uma roda, ele mal consegue mover o próprio robô: qualquer resistência o faz parar.

A **caixa de redução** é um trem de engrenagens entre o motor e o eixo de saída que faz uma troca: **sacrifica velocidade para multiplicar torque**. Uma redução de **1:30** significa que o motor gira 30 voltas para o eixo dar 1 — e, idealmente, o torque no eixo sai ~30 vezes maior.

```
velocidade do eixo = velocidade do motor ÷ redução
torque do eixo     ≈ torque do motor × redução
```

É o mesmo princípio das marchas da bicicleta: marcha leve (redução alta) sobe ladeira devagar com pouco esforço; marcha pesada (redução baixa) voa no plano, mas trava na subida. Não existe redução "melhor" em absoluto — **existe a redução certa para cada tarefa**.

### 5.1.3 Experimento: comparando reduções

É por isso que este projeto adquire N20 em **reduções diferentes** (por exemplo 1:10, 1:30 e 1:50): para você **descobrir medindo**, e não decorando, qual serve a cada robô.

**Protocolo do experimento** (registre tudo na planilha do Capítulo 6):

1. Monte o mesmo robô com cada par de reduções, sem alterar mais nada.
2. **Velocidade:** cronometre o robô percorrendo uma reta de 2 m. Calcule m/s.
3. **Arrancada:** meça o tempo até cruzar uma marca a 30 cm, partindo do repouso.
4. **Força de empurrão:** o robô empurra uma caixa com pesos crescentes; anote a maior carga que ele move.
5. **Corrente:** meça com o multímetro a corrente dos motores em movimento livre e travados (rapidamente!) em cada redução.

Ao final, responda com os *seus* dados: qual redução você escolhe para o seguidor de linha? E para o sumô? Por quê?

> 🧪 **Teste o que você fez** — Antes do experimento, valide o instrumental: o cronômetro, a marcação da pista de 2 m e a repetibilidade (três corridas da mesma configuração dão tempos parecidos? Se variam muito, o problema é o método, não o motor).

## 5.2 Fiação e solda

### Bitolas e cores

A regra prática: **fio fino para sinal, fio grosso para potência**.

| Uso | Bitola sugerida |
|---|---|
| Sinais (sensores, IN1–IN4) | 26–28 AWG (jumpers padrão) |
| Alimentação lógica (5 V) | 24–26 AWG |
| Bateria → chave → L298N | **18–20 AWG** |

Convenção de cores inegociável: **vermelho = positivo, preto = GND**. Sinais nas demais cores. Um robô com fiação colorida corretamente se depura em minutos; um robô "tudo azul" se depura em horas.

### Solda: técnica essencial

1. Ferro limpo e estanhado (ponta brilhante).
2. **Aqueça a junta** (terminal + fio), não o estanho: encoste o ferro nas duas partes por 1–2 s e só então alimente o estanho **na junta**.
3. Solda boa é brilhante e cônica; solda fosca e globular é "solda fria" — refaça.
4. **Termorretrátil sempre**: enfie o tubo no fio *antes* de soldar, deslize sobre a junta pronta e aqueça.

### Placa ilhada

A **placa ilhada** (perfurada, com uma ilha de cobre por furo) é a ponte entre a protoboard e a placa de circuito profissional: componentes soldados de um lado, trilhas construídas com estanho e pedaços de fio do outro. Planeje o layout no papel antes de soldar, e corte/desbaste a placa nas dimensões que o projeto pedir. Você usará essa técnica no desafio da seção 5.6.

> 🧪 **Teste o que você fez** — Exercício de solda: emende dois fios de 20 AWG (emenda em linha, soldada e isolada com termorretrátil) e solde um conector qualquer numa placa ilhada com duas trilhas de estanho. Teste de continuidade com o multímetro em tudo. Puxe a emenda com força — aguentou?

## 5.3 Baterias

### LiPo: potência com responsabilidade

A bateria do seguidor é uma **LiPo 2S 2200 mAh 30C** (7,4 V nominal, XT60, 75 × 23 × 18 mm, ~100 g). Os "2S" indicam 2 células em série (3,7 V nominais cada); "30C" é a taxa de descarga — essa bateria entrega dezenas de ampères sem esforço, ordens de grandeza acima do que o robô pede.

**Regras de segurança — leitura obrigatória:**

1. **Nunca descarregue abaixo de 3,0 V por célula** (6,0 V no pack; alarme prático em 6,6 V). Descarga profunda **destrói** a LiPo e a torna perigosa.
2. **Carregue somente em carregador balanceado** próprio para LiPo, usando o conector de balanceamento, **nunca sem supervisão**.
3. Armazene com ~3,8 V/célula ("storage"), em local fresco, idealmente em saco anti-chama (LiPo bag).
4. Bateria **inchada, amassada ou perfurada**: fora de uso, descarte adequado. Sem exceção.
5. No robô, a bateria fica **firmemente presa** (velcro pelas janelas do suporte) — bateria solta em colisão é o pior cenário.

> 🧪 **Teste o que você fez** — Com o multímetro: tensão total no XT60 e tensão de cada célula no conector de balanceamento. As células estão equilibradas (diferença < 0,05 V)? Registre esses valores como referência de "bateria saudável".

### Regulação (revisão)

A arquitetura definida no Capítulo 1: bateria → **chave geral** → dois ramos — LM2596 em 5 V para a lógica; direto para o L298N (que entrega ~6 V aos motores após sua queda interna). O ajuste do LM2596 com multímetro **antes de conectar carga** é obrigatório.

## 5.4 🔧 Desafio de projeto: módulo de distribuição de energia

Este é o **desafio de desenvolvimento** do seguidor de linha — a aula mostra *o que* precisa ser feito; **como** fazer da melhor forma é problema seu.

### O problema

O robô precisa de um ponto único de gestão de energia que: **(a)** receba o conector XT60 da bateria; **(b)** tenha uma **chave geral liga/desliga**; **(c)** divida a energia em dois ramos — um passando pelo LM2596 (5 V → Arduino e sensores) e outro direto ao L298N (motores).

```
XT60 (bateria) ──→ CHAVE GERAL ──┬──→ LM2596 ──→ 5 V (Arduino + sensores)
                                 └──→ direto ──→ L298N (motores)
```

### Requisitos obrigatórios

- Todas as conexões **soldadas e isoladas**;
- Chave **acessível com o robô completamente montado** (regra prática de competição: energizar só quando autorizado);
- Componentes **firmemente fixados** — nada solto para vibrar;
- Compatível com a fixação no chassi;
- Polaridade **à prova de erro** (conector com chaveamento mecânico, cores corretas, marcações).

### Critérios de qualidade

O que separa uma peça aceitável de uma excelente: organização dos cabos, facilidade de manutenção (dá para trocar um módulo sem dessoldar tudo?), peso, robustez à trepidação e clareza (outra pessoa entende sua peça só de olhar?).

### Implementação de referência (do professor)

Uma solução validada, para servir de parâmetro — não de gabarito: **placa ilhada** com o conector da bateria, a chave e **bornes** (conectores de parafuso) soldados, trilhas construídas em estanho, placa **desbastada** nas dimensões adequadas e fixada ao chassi. Os bornes tornam os ramos de saída desmontáveis para manutenção, sem dessoldar.

Placa de distribuição — vista superior
*(foto a ser adicionada)*

Placa de distribuição — vista inferior (trilhas)
*(foto a ser adicionada)*

Sua solução pode seguir esse caminho, projetar uma peça 3D porta-componentes, ou combinar os dois. **Soluções diferentes são bem-vindas desde que cumpram os requisitos.**

> 🧪 **Teste o que você fez** — Sequência de validação, nesta ordem e **sem o Arduino conectado**:
> 1. Continuidade (bip) da entrada à saída de cada ramo, com a chave ligada; ausência de continuidade com a chave desligada.
> 2. Ausência de curto entre positivo e GND em ambos os ramos.
> 3. Conecte a bateria: mede a tensão dela no ramo dos motores?
> 4. Mede **5,0 V estáveis** na saída do LM2596?
> 5. Só então conecte o Arduino e o L298N.

## 5.5 Integração final e centro de massa

Com todos os subsistemas testados, a montagem final segue a ordem: peça de energia → L298N → Arduino → sensor IR → bateria por último. Diretrizes:

- **Cabos de potência longe dos cabos de sinal** (ruído dos motores induz erro nos sensores analógicos; se notar leituras "dançando" com os motores girando, esse é o primeiro suspeito — um capacitor de 100 nF entre os terminais de cada motor ajuda).
- **Centro de massa:** no seguidor, levemente à frente do eixo das rodas melhora a tração e o comportamento em curva; a posição da bateria (o item mais pesado) é o seu principal ajuste.
- Nada pode encostar nas rodas nem arrastar no chão (exceto o que deve).

> 🧪 **Teste o que você fez** — O teste de integração completo: robô montado, suspenso — todas as funções de motor respondem? Sensores lendo normalmente **com os motores girando**? Agora no chão: anda reto? A chave desliga tudo instantaneamente?

## 5.6 Diagnóstico de problemas comuns

| Sintoma | Suspeitos, na ordem |
|---|---|
| Nada liga | chave; solda fria na placa de energia; bateria descarregada |
| Arduino liga, motores não | alimentação do L298N; jumper ENA/ENB; funções IN invertidas |
| Um motor mais lento | conexão frouxa; diferença natural entre motores (compense por software) |
| Sensores com leitura instável | ruído dos motores; distância ao solo; luz ambiente forte |
| Robô reinicia sozinho | queda de tensão na arrancada — bateria fraca ou fiação de potência fina demais |
| Anda torto | montagem desalinhada das rodas; PWM mínimo diferente entre motores |

Método de diagnóstico: **volte aos testes unitários**. Cada componente tem seu teste isolado do repositório — rode-os na ordem inversa da integração até achar o culpado.

## 5.7 Soluções do aluno

Esta seção é sua. Documente aqui (no fork do repositório da sua equipe) cada decisão que você tomou diferente da referência: o layout da sua placa de energia, a redução que escolheu e os dados que justificam, melhorias no chassi, truques de montagem. O formato mínimo de cada registro: **o problema → as alternativas consideradas → a escolha → o resultado medido**. Engenharia é isso.

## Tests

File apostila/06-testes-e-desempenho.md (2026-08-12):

# Capítulo 6 — Testes e desempenho

Construir o robô é metade do caminho. A outra metade — a que separa quem participa de quem compete — é **medir, ajustar e repetir**. Este capítulo transforma os testes pontuais dos capítulos anteriores em um método.

## 6.1 A metodologia: testar → medir → ajustar → repetir

O ciclo de melhoria tem quatro regras:

1. **Mude uma coisa por vez.** Se você alterou a velocidade E a posição da bateria E o limiar do sensor, e o robô melhorou — o que causou a melhora? Você não sabe. Um ajuste por rodada.
2. **Meça antes e depois.** "Parece mais rápido" não é dado. Cronômetro, régua e planilha são.
3. **Repita cada medição** pelo menos 3 vezes e use a média — robôs reais variam entre corridas.
4. **Registre tudo**, inclusive (principalmente!) o que piorou. O registro do que não funciona economiza o tempo de quem vier depois — e o seu daqui a duas semanas.

Este é o mesmo raciocínio dos testes de software: cada componente já passou pelo seu teste unitário (blocos 🧪 dos capítulos anteriores); agora fazemos **testes de sistema** e **medição de desempenho**.

## 6.2 Métricas do seguidor de linha

| Métrica | Como medir | Meta de referência |
|---|---|---|
| **Tempo de volta** | cronômetro na pista de treino, 3+ voltas, média | quanto menor, melhor — acompanhe a evolução |
| **Taxa de voltas válidas** | válidas ÷ tentativas (últimas 10) | ≥ 80 % antes de pensar em velocidade |
| **Comportamento em curva** | filmar o robô no raio mínimo (100 mm) | sem sair da linha; oscilação mínima |
| **Cruzamentos** | trecho de teste com cruzamento a 90° | atravessa reto, sem "pegar" a linha transversal |
| **Parada na chegada** | 10 chegadas seguidas | 10/10 paradas dentro da área, 2 s imóvel |
| **Autonomia** | voltas contínuas até a bateria alarmar | cobre com folga uma tomada de tempo de 5 min |

**A ordem certa de otimização:** primeiro **confiabilidade** (taxa de voltas válidas), depois **velocidade**. Um robô que faz 25 s com 100 % de validade vence um que faz 18 s e cai metade das vezes — lembre: vale a **melhor volta válida**, mas você só tem 3 tentativas em 5 minutos.

## 6.3 Métricas do sumô

| Métrica | Como medir |
|---|---|
| **Resposta à borda** | robô a toda velocidade contra a Tawara de treino: escapa sempre? distância percorrida sobre o branco antes de reagir |
| **Detecção do oponente** | alvo de 10 cm em posições variadas do dohyo: em quanto tempo o robô o encontra a partir do giro de busca? |
| **Força de empurrão** | empurra um peso de referência (500 g, depois mais) do centro até fora do dohyo |
| **Largada** | tempo entre o sinal do juiz (IR) e o primeiro movimento |
| **Rounds simulados** | melhor de 3 contra oponente (outro robô ou "sparring" controlado): registre resultado e causa de cada ponto |

> 🚧 Metas quantitativas de referência serão consolidadas com a definição do hardware do sumô (**em desenvolvimento** — ver Capítulo 4).

## 6.4 Registro de resultados

Crie na pasta da sua equipe uma planilha (ou arquivo Markdown) de **diário de testes** com, no mínimo, as colunas:

```
data | versão do código | configuração (redução, PWM, limiares...) | métrica | valores (3x) | média | observações
```

Duas disciplinas que se pagam sozinhas: **versione o código** a cada mudança relevante (commits pequenos e descritivos no Git — o repositório já está no GitHub, use-o); e anote a **configuração completa** junto de cada medição, porque "o tempo bom da semana passada" sem a configuração que o produziu é um tempo perdido.

## 6.5 Ensaio geral: simulando o dia da competição

Nas semanas finais, os treinos devem reproduzir as condições da prova — inclusive as pressões de tempo do regulamento.

### Simulação do seguidor de linha

Reproduza a tomada de tempo oficial: **5 minutos no relógio, 3 tentativas**, pista limpa no início e ninguém toca o robô após cada largada. Pratique as decisões reais: se a primeira volta foi válida mas lenta, arrisca ajustar parâmetros para a segunda? (Lembre: ajustes só **entre** tentativas, e só pelos meios já embarcados no robô.)

### Simulação do sumô

Reproduza um round completo com os tempos-limite do regulamento, que geram penalidade (Keikoku) se estourados:

- Apresentação na arena após a chamada: **3 minutos**;
- Apresentação no dohyo após a inspeção: **1 minuto**;
- Energização + configuração de estratégia: **30 segundos**;
- Intervalo entre rounds: **30 segundos**.

Treine a coreografia: posicionar atrás da Shikiri-sen, sair da área imediatamente, aguardar o sinal IR do juiz, e — crucial — **o robô só pode se mover após o start** (movimento antes do início é Keikoku).

### Checklist do dia da competição

**Levar:**

- [ ] Robô(s) + robô/peças reserva do que for crítico
- [ ] Baterias carregadas (todas) + carregador balanceado + LiPo bag
- [ ] Notebook com a IDE, os códigos (repositório clonado!) e cabo micro-USB
- [ ] Ferramentas: chaves, ferro de solda, estanho, multímetro, fita, abraçadeiras
- [ ] Peças sobressalentes: parafusos, jumpers, sensores, pneus reserva
- [ ] **Óculos de proteção, calça e calçado fechado** (obrigatórios no sumô)
- [ ] Documentos e comprovantes exigidos pelo edital

**Ao chegar / antes de competir:**

- [ ] Conferir horários de briefing (presença obrigatória de um representante) e inspeção
- [ ] Calibrar os sensores **na pista/dohyo oficial** (iluminação e superfície diferem das de treino)
- [ ] Limpar os pneus (retirar da roda, lavar com água e sabão, secar ao ar — recuperam a aderência original)
- [ ] Verificar tensão da bateria; trocar por uma cheia antes de cada rodada
- [ ] Seguidor: conferir aperto de todos os parafusos (vibração solta tudo)
- [ ] Sumô: passar o robô pela caixa de inspeção e pela balança da equipe antes da oficial

**Regras de ouro na prova:**

1. Não regrave código minutos antes de competir sem testar — a versão estável conhecida vence a versão "melhorada" não testada.
2. Anote os resultados de cada tentativa/round: o aprendizado da competição alimenta o ciclo do próximo ano.
3. Respeite juízes, organização e adversários — além de ser regra (com desclassificação prevista), é o espírito do evento.

## O que você leva deste capítulo — e da apostila

Um método: componentes testados isoladamente, sistema medido com números, melhorias validadas uma a uma, e um robô que chega ao dia da prova ensaiado, documentado e com plano B. O resto — a adrenalina da arquibancada, o barulho do dohyo, a torcida — o TRIF entrega.

Boa competição. 🏆

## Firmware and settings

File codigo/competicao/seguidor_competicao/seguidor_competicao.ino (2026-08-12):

/*
 * ============================================================
 *  COMPETIÇÃO — SEGUIDOR DE LINHA
 * ============================================================
 * Versão otimizada para VENCER. Estude-a depois de dominar o playground.
 *
 * Recursos:
 *   - Leitura calibrada e normalizada dos 8 canais
 *   - Posição contínua da linha por média ponderada (0..7000)
 *   - Controle PID (proporcional + integral + derivativo)
 *   - Tratamento de cruzamentos (segue reto)
 *   - Recuperação de linha perdida (procura no lado em que sumiu)
 *   - Perfil de velocidade: acelera em trecho estável, reduz em curva
 *   - Parada automática na marcação de chegada (regra dos 2 s)
 *
 * TODOS os parâmetros de ajuste estão agrupados abaixo — no dia da
 * competição, é SÓ ali que se mexe.
 */

// ==================== PARÂMETROS DE AJUSTE ====================
// --- Velocidades (0..255) ---
const int VEL_BASE      = 170;   // velocidade média de trabalho
const int VEL_MAX_RETA  = 230;   // teto em trecho estável (reta)
const int VEL_MIN_CURVA = 120;   // piso em curva fechada
const int PWM_MINIMO    = 60;    // limiar de partida do SEU motor (medido!)

// --- PID (ajuste nesta ordem: KP -> KD -> KI) ---
float KP = 0.045;    // reação proporcional ao erro
float KD = 0.60;     // amortecimento (reage à VARIAÇÃO do erro)
float KI = 0.0005;   // corrige desvio persistente (use com moderação)
const int LIMITE_INTEGRAL = 4000;  // anti-windup

// --- Chegada e pista ---
const int  AVANCO_CHEGADA_MS   = 220;  // avanço após a marcação p/ entrar na área
const long TRAVA_CHEGADA_MS    = 1500; // ignora chegada nesse início (largada fica na área!)
const int  CICLOS_RETA         = 60;   // ciclos com erro pequeno p/ considerar "reta"
const long TEMPO_CALIBRACAO_MS = 5000;
// ==============================================================

// ---- Pinos (Anexo B da apostila) ----
const int PINOS_SENSOR[8] = {A0, A1, A2, A3, A4, A5, 4, 6};
const int IN1 = 2, IN2 = 3, ENA = 9;
const int IN3 = 7, IN4 = 8, ENB = 10;
const int PINO_BOTAO = 5;
const int PINO_LED = 13;

// ---- Estado global ----
int  minimo[8], maximo[8];
int  valorNorm[8];                 // últimas leituras normalizadas (0..1000, 1000 = vendo linha)
int  ultimaPosicao = 3500;
long erroAnterior = 0;
long somaErro = 0;
int  ciclosEstaveis = 0;
long instanteLargada = 0;

// -------------------- SENSORES --------------------
void calibrar() {
  for (int i = 0; i < 8; i++) { minimo[i] = 1023; maximo[i] = 0; }
  digitalWrite(PINO_LED, HIGH);
  long inicio = millis();
  while (millis() - inicio < TEMPO_CALIBRACAO_MS) {
    for (int i = 0; i < 8; i++) {
      int leitura = analogRead(PINOS_SENSOR[i]);
      if (leitura < minimo[i]) minimo[i] = leitura;
      if (leitura > maximo[i]) maximo[i] = leitura;
    }
  }
  digitalWrite(PINO_LED, LOW);
}

// Atualiza valorNorm[] — linha BRANCA: 1000 = canal sobre a linha
void lerSensores() {
  for (int i = 0; i < 8; i++) {
    int leitura = analogRead(PINOS_SENSOR[i]);
    leitura = constrain(leitura, minimo[i], maximo[i]);
    valorNorm[i] = 1000 - map(leitura, minimo[i], maximo[i], 0, 1000);
  }
}

// Posição da linha 0..7000 (3500 = centro); memória do lado ao perdê-la
int calcularPosicao() {
  long somaPonderada = 0, somaValores = 0;
  bool linhaVista = false;
  for (int i = 0; i < 8; i++) {
    if (valorNorm[i] > 200) linhaVista = true;
    somaPonderada += (long)valorNorm[i] * i * 1000;
    somaValores   += valorNorm[i];
  }
  if (!linhaVista) return (ultimaPosicao < 3500) ? 0 : 7000;
  ultimaPosicao = somaPonderada / somaValores;
  return ultimaPosicao;
}

int quantosVendoLinha() {
  int n = 0;
  for (int i = 0; i < 8; i++) if (valorNorm[i] > 500) n++;
  return n;
}

// Chegada: marcação à DIREITA da linha, centro na linha, esquerda limpa.
// (Cruzamento acende os dois lados e é tratado à parte.)
bool marcacaoChegada() {
  bool dir = valorNorm[6] > 500 || valorNorm[7] > 500;
  bool esq = valorNorm[0] > 500 || valorNorm[1] > 500;
  bool centro = valorNorm[3] > 500 || valorNorm[4] > 500;
  return dir && centro && !esq;
}

// -------------------- MOTORES --------------------
void motores(int velEsq, int velDir) {
  // aplica o PWM mínimo de partida (evita a "zona morta" do motor)
  if (velEsq > 0 && velEsq < PWM_MINIMO) velEsq = PWM_MINIMO;
  if (velDir > 0 && velDir < PWM_MINIMO) velDir = PWM_MINIMO;
  velEsq = constrain(velEsq, -255, 255);
  velDir = constrain(velDir, -255, 255);

  digitalWrite(IN1, velEsq >= 0 ? HIGH : LOW);
  digitalWrite(IN2, velEsq >= 0 ? LOW : HIGH);
  analogWrite(ENA, abs(velEsq));
  digitalWrite(IN3, velDir >= 0 ? HIGH : LOW);
  digitalWrite(IN4, velDir >= 0 ? LOW : HIGH);
  analogWrite(ENB, abs(velDir));
}

void pararDefinitivo() {
  motores(0, 0);
  digitalWrite(PINO_LED, HIGH);   // sinaliza "cheguei"
  while (true) { }                // imóvel: regra dos 2 segundos garantida
}

// -------------------- PROGRAMA --------------------
void setup() {
  pinMode(IN1, OUTPUT); pinMode(IN2, OUTPUT); pinMode(ENA, OUTPUT);
  pinMode(IN3, OUTPUT); pinMode(IN4, OUTPUT); pinMode(ENB, OUTPUT);
  pinMode(PINO_BOTAO, INPUT_PULLUP);
  pinMode(PINO_LED, OUTPUT);

  calibrar();
  while (digitalRead(PINO_BOTAO) == HIGH) { }   // largada
  delay(300);
  instanteLargada = millis();
}

void loop() {
  lerSensores();

  // ---- 1) Chegada (ignorada nos primeiros instantes: a largada É na área) ----
  if (millis() - instanteLargada > TRAVA_CHEGADA_MS && marcacaoChegada()) {
    motores(VEL_BASE, VEL_BASE);
    delay(AVANCO_CHEGADA_MS);
    pararDefinitivo();
  }

  // ---- 2) Cruzamento: muitos sensores ativos -> atravessa RETO ----
  if (quantosVendoLinha() >= 5) {
    motores(VEL_BASE, VEL_BASE);
    ciclosEstaveis = 0;
    return;
  }

  // ---- 3) PID sobre a posição da linha ----
  int posicao = calcularPosicao();
  long erro = (long)posicao - 3500;            // negativo = linha à esquerda

  somaErro += erro;
  somaErro = constrain(somaErro, -LIMITE_INTEGRAL, LIMITE_INTEGRAL);  // anti-windup
  long derivada = erro - erroAnterior;
  erroAnterior = erro;

  long correcao = KP * erro + KI * somaErro + KD * derivada;

  // ---- 4) Perfil de velocidade: reta acelera, curva segura ----
  if (abs(erro) < 400) { if (ciclosEstaveis < 1000) ciclosEstaveis++; }
  else ciclosEstaveis = 0;

  int velAtual;
  if (ciclosEstaveis > CICLOS_RETA)  velAtual = VEL_MAX_RETA;   // reta confirmada
  else if (abs(erro) > 2000)         velAtual = VEL_MIN_CURVA;  // curva fechada
  else                               velAtual = VEL_BASE;

  // correção positiva = linha à direita = acelera a esquerda / segura a direita
  motores(velAtual + correcao, velAtual - correcao);
}

/*
 * ROTEIRO DE AJUSTE DO PID (um parâmetro por vez, medindo o tempo de volta):
 * 1. KI = 0, KD = 0. Suba KP até o robô seguir curvas fechadas — se oscilar
 *    ("rabear") nas retas, passou do ponto: recue ~20%.
 * 2. Suba KD até a oscilação residual sumir. KD alto demais deixa o robô
 *    "nervoso" com imperfeições da pista.
 * 3. KI só se o robô fizer curva "por fora" de forma persistente. Valores
 *    minúsculos; o anti-windup protege, mas não abuse.
 * 4. Só então mexa nas velocidades. Confiabilidade primeiro, tempo depois.
 */

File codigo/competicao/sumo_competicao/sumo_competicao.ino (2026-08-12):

/*
 * ============================================================
 *  COMPETIÇÃO — SUMÔ AUTÔNOMO (500 g)
 * ============================================================
 * Versão otimizada para VENCER, conforme o regulamento do TRIF:
 *
 *   - Largada e parada pelo CONTROLE REMOTO DO JUIZ (IR, protocolo Sony):
 *       Tecla 1 = Pronto | Tecla 2 = Start | Tecla 3 = Stop
 *   - Estado STOP PERMANENTE: só sai desligando e religando o robô (regra!)
 *   - Borda (Tawara) verificada em alta prioridade a cada ciclo
 *   - Busca ativa em arco (avança varrendo, em vez de girar parado)
 *   - Estado de EMPURRÃO: mantém pressão mesmo se o sensor piscar
 *   - Largada explosiva no Start
 *
 * Hardware de referência (chassi/driver/bateria do sumô: EM DESENVOLVIMENTO —
 * ajuste pinos e drivers ao robô definitivo):
 *   Receptor IR 38 kHz no pino 3 | bordas A0/A1 | oponente pino 12
 *   Driver: IN1=4, IN2=5, PWM_ESQ=9 | IN3=6, IN4=8, PWM_DIR=10
 *
 * Biblioteca: IRremote (Gerenciador de Bibliotecas da IDE).
 * Os CÓDIGOS das teclas variam por controle: descubra os do controle usado
 * com o teste unitário 08 e atualize as constantes COMANDO_*.
 */

#include <IRremote.hpp>

// ==================== PARÂMETROS DE AJUSTE ====================
// --- Códigos do controle Sony (descubra os SEUS com o teste 08!) ---
const uint16_t COMANDO_PRONTO = 0x00;  // tecla 1 (Sony: dígito 1 = comando 0)
const uint16_t COMANDO_START  = 0x01;  // tecla 2
const uint16_t COMANDO_STOP   = 0x02;  // tecla 3

// --- Velocidades (0..255) ---
const int VEL_ATAQUE      = 255;
const int VEL_EMPURRAO    = 255;
const int VEL_BUSCA_RAP   = 170;   // roda externa na busca em arco
const int VEL_BUSCA_LEN   = 90;    // roda interna na busca em arco
const int VEL_ESCAPE      = 220;
const int VEL_LARGADA     = 255;

// --- Tempos (ms) ---
const int TEMPO_LARGADA   = 250;   // avanço cego explosivo no Start
const int TEMPO_RE        = 350;
const int TEMPO_GIRO_ESC  = 280;
const long MEMORIA_EMPURRAO = 600; // mantém empurrão até X ms sem ver o oponente

// --- Sensores ---
const int LIMIAR_BORDA = 500;      // meça com o teste unitário 06!
// ==============================================================

// ---- Pinos ----
const int PINO_IR_JUIZ   = 3;
const int PINO_BORDA_ESQ = A0;
const int PINO_BORDA_DIR = A1;
const int PINO_OPONENTE  = 12;
const int IN1 = 4, IN2 = 5, PWM_ESQ = 9;
const int IN3 = 6, IN4 = 8, PWM_DIR = 10;
const int PINO_LED = 13;

// ---- Estados do robô (conforme o fluxo do regulamento) ----
enum Estado { AGUARDANDO, LUTANDO, TRAVADO };
Estado estado = AGUARDANDO;

long ultimaVisaoOponente = -10000;  // instante em que o oponente foi visto por último
int  sentidoBusca = 1;              // 1 = arco pela direita, -1 = pela esquerda

// -------------------- MOTORES --------------------
void motores(int velEsq, int velDir) {
  velEsq = constrain(velEsq, -255, 255);
  velDir = constrain(velDir, -255, 255);
  digitalWrite(IN1, velEsq >= 0 ? HIGH : LOW);
  digitalWrite(IN2, velEsq >= 0 ? LOW : HIGH);
  analogWrite(PWM_ESQ, abs(velEsq));
  digitalWrite(IN3, velDir >= 0 ? HIGH : LOW);
  digitalWrite(IN4, velDir >= 0 ? LOW : HIGH);
  analogWrite(PWM_DIR, abs(velDir));
}

void parar() { motores(0, 0); }

// -------------------- SENSORES --------------------
bool bordaEsq() { return analogRead(PINO_BORDA_ESQ) < LIMIAR_BORDA; }
bool bordaDir() { return analogRead(PINO_BORDA_DIR) < LIMIAR_BORDA; }
bool oponenteVisto() { return digitalRead(PINO_OPONENTE) == LOW; }

// -------------------- JUIZ (IR) --------------------
// Lê o receptor; retorna o comando Sony recebido ou 0xFFFF se nada novo
uint16_t lerComandoJuiz() {
  if (IrReceiver.decode()) {
    uint16_t cmd = 0xFFFF;
    if (IrReceiver.decodedIRData.protocol == SONY) {
      cmd = IrReceiver.decodedIRData.command;
    }
    IrReceiver.resume();
    return cmd;
  }
  return 0xFFFF;
}

// STOP tem prioridade máxima e é PERMANENTE (regra do TRIF):
// desligar e religar o robô é a única saída deste estado.
void verificarStop() {
  uint16_t cmd = lerComandoJuiz();
  if (cmd == COMANDO_STOP) {
    parar();
    estado = TRAVADO;
    while (true) {                      // travado para sempre
      digitalWrite(PINO_LED, HIGH); delay(200);
      digitalWrite(PINO_LED, LOW);  delay(200);   // pisca = "recebi o Stop"
    }
  }
}

// -------------------- MANOBRAS --------------------
void escapeDaBorda(bool foiEsquerda) {
  motores(-VEL_ESCAPE, -VEL_ESCAPE);      // ré imediata
  delay(TEMPO_RE);
  verificarStop();                        // nunca fique muito tempo sem ouvir o juiz
  if (foiEsquerda) motores(VEL_ESCAPE, -VEL_ESCAPE);  // gira p/ longe da borda
  else             motores(-VEL_ESCAPE, VEL_ESCAPE);
  delay(TEMPO_GIRO_ESC);
  sentidoBusca = -sentidoBusca;           // varia a busca após cada escape
}

// -------------------- PROGRAMA --------------------
void setup() {
  pinMode(IN1, OUTPUT); pinMode(IN2, OUTPUT); pinMode(PWM_ESQ, OUTPUT);
  pinMode(IN3, OUTPUT); pinMode(IN4, OUTPUT); pinMode(PWM_DIR, OUTPUT);
  pinMode(PINO_OPONENTE, INPUT);
  pinMode(PINO_LED, OUTPUT);
  IrReceiver.begin(PINO_IR_JUIZ, ENABLE_LED_FEEDBACK);

  parar();  // regra: o robô NÃO pode se mover antes do Start do juiz
}

void loop() {
  // =========== AGUARDANDO: imóvel até o Start do juiz ===========
  if (estado == AGUARDANDO) {
    parar();
    uint16_t cmd = lerComandoJuiz();
    if (cmd == COMANDO_PRONTO) {
      digitalWrite(PINO_LED, HIGH);       // LED fixo = "Pronto" confirmado
    } else if (cmd == COMANDO_START) {
      digitalWrite(PINO_LED, LOW);
      // LARGADA EXPLOSIVA: avanço cego para ganhar o centro do dohyo
      motores(VEL_LARGADA, VEL_LARGADA);
      delay(TEMPO_LARGADA);
      estado = LUTANDO;
    }
    return;
  }

  // =========== LUTANDO ===========
  verificarStop();                        // 1º: o juiz manda

  // 2º: a borda — prioridade sobre qualquer combate
  bool be = bordaEsq(), bd = bordaDir();
  if (be || bd) {
    escapeDaBorda(be);
    return;
  }

  // 3º: combate
  long agora = millis();
  if (oponenteVisto()) {
    ultimaVisaoOponente = agora;
    motores(VEL_ATAQUE, VEL_ATAQUE);                    // ATAQUE
  } else if (agora - ultimaVisaoOponente < MEMORIA_EMPURRAO) {
    // acabou de "perder" o oponente: provavelmente estamos COLADOS nele
    // (sensor muito perto não enxerga) -> mantém o EMPURRÃO
    motores(VEL_EMPURRAO, VEL_EMPURRAO);
  } else {
    // BUSCA ATIVA: avança em arco varrendo a arena (mais agressivo
    // e imprevisível que girar parado no centro)
    if (sentidoBusca > 0) motores(VEL_BUSCA_RAP, VEL_BUSCA_LEN);
    else                  motores(VEL_BUSCA_LEN, VEL_BUSCA_RAP);
  }
}
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

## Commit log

2026-08-12 Versão inicial da apostila
    [calco_comprimento_5mm.stl, calco_largura_1mm.stl, chassi_base.stl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]
2026-08-12 Corrige estrutura de pastas
    [calco_comprimento_5mm.stl, calco_largura_1mm.stl, chassi_base.stl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]
